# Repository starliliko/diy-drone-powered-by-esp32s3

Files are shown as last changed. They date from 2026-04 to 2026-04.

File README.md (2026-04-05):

# DIY-Drone

> 基于 ESP-Drone 二次开发的室内无刷四旋翼无人机，涵盖飞控固件、机架设计与地面站全链路。

本项目以 Espressif [ESP-Drone](https://github.com/espressif/esp-drone) 飞控工程为基础，将原有微型有刷方案重构为 **更大轴距、无刷电机驱动** 的四旋翼平台，并围绕该平台完成了飞控适配、传感器链路优化、安全机制完善、机架结构设计以及地面站调试闭环搭建。

## 项目亮点

| 方向 | 内容 |
|---|---|
| **飞控适配** | 基于 ESP32-S3 / ESP-IDF / FreeRTOS，对 ESP-Drone 飞控架构进行重构与平台适配 |
| **传感器链路** | 接入 BMI088（SPI）、气压计、光流，完成中断驱动采集、零偏校准、低通 / 陷波滤波 |
| **状态估计与控制** | 卡尔曼估计器、PID 级联控制、多飞行模式（姿态 / 定高 / 定点）、多控制源优先级切换 |
| **安全机制** | 遥控失联降级、控制源超时切换、解锁保护、异常紧急停机 |
| **机架设计** | Autodesk Inventor 建模 → 3D 打印打样 → 实机装配 → 结构迭代 |
| **地面站** | Node.js + WebSocket，实时遥测、3D 姿态可视化、远程控制、电机测试 |

## 仓库结构

```text
DIY-DRONE/
├── docs/                  # 项目文档与开发记录
├── mechanical/            # 机架 CAD 源文件、导出图纸、打印件
│   ├── 新版 4.5/          #   当前版本
│   └── 旧完整版/          #   早期版本备份
├── software/
│   ├── firmware/          # 飞控固件（ESP-IDF 工程）
│   └── groundstation/     # 地面站（Node.js）
├── LICENSE
└── README.md
```

## 系统架构

```text
┌──────────────┐  TCP/WiFi   ┌──────────────┐  WebSocket  ┌──────────────┐
│   ESP32-S3   │ ──────────▶ │  Node.js     │ ──────────▶ │   浏览器      │
│   飞控固件    │ ◀────────── │  地面站服务    │ ◀────────── │   Web UI     │
└──────────────┘   控制指令   └──────────────┘   操作指令   └──────────────┘
       │
       ├── BMI088（SPI）· 加速度 / 陀螺仪
       ├── 气压计（I2C）· 高度估计
       ├── 光流（UART）· 水平位置
       └── SBUS 遥控器 · 最高优先级控制源
```

### 飞控固件 — `software/firmware/`

- 传感器驱动与中断采集
- 卡尔曼状态估计、PID 级联控制
- 多飞行模式（姿态稳定 / 定高 / 定点）
- 多控制源优先级管理（SBUS > TCP > CRTP）
- 失联降级、解锁保护、紧急停机等安全链路

### 地面站 — `software/groundstation/`

- 遥测仪表盘与 Three.js 3D 姿态可视化
- 解锁 / 起飞 / 降落 / 紧急停止 等飞行控制
- 独立电机推力测试
- WebSocket 实时双向通信

### 机架 — `mechanical/`

- Autodesk Inventor 全参数化建模
- 电机 / 桨叶 / 电池 / 电调安装适配
- 重心布局、减振结构、强度优化
- 3D 打印打样与实物装配验证

## 技术栈

| 类别 | 技术 |
|---|---|
| MCU / 平台 | ESP32-S3 |
| 固件框架 | ESP-IDF 5.x · FreeRTOS |
| 传感器 | BMI088 · BMP388 · PMW3901 光流 |
| 通信接口 | SPI · I2C · UART · TCP · WiFi |
| 控制与估计 | PID 级联 · 扩展卡尔曼滤波 · 多模式状态管理 |
| 地面站 | Node.js · Express · WebSocket · Three.js |
| 机械设计 | Autodesk Inventor · FDM 3D 打印 |

## 当前进展

- [x] 无刷四旋翼整机方案设计与样机装配
- [x] 飞控固件迁移、传感器接入与基础飞行功能打通
- [x] 地面站开发与调试链路搭建
- [x] 基础实飞测试
- [ ] 飞行稳定性与控制参数持续优化
- [ ] 地面站功能完善（数据记录 / 回放 / 图表）
- [ ] 机架结构持续迭代（减振、重心、安装布局）

## 声明

本项目基于 [ESP-Drone](https://github.com/espressif/esp-drone) 飞控工程进行二次开发，部分飞控架构与算法实现参考了相关开源飞控项目。本仓库重点展示在此基础上完成的平台重构、软硬件适配、整机设计与实机调试工作。

## 许可证

[GPL-3.0](LICENSE)

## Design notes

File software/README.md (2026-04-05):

# Software — 软件系统

> 飞控固件与地面站，构成 DIY-Drone 的完整软件链路。

## 目录结构

```text
software/
├── firmware/          # 飞控固件（ESP-IDF 工程）
└── groundstation/     # 地面站（Node.js Web 应用）
```

## 飞控固件 — `firmware/`

基于 ESP-IDF 5.x 构建，运行在 ESP32-S3 上。

| 模块 | 说明 |
|---|---|
| 传感器驱动 | BMI088（SPI）、气压计（I2C）、光流（UART）中断采集与滤波 |
| 状态估计 | 扩展卡尔曼滤波器，融合 IMU / 气压 / 光流 |
| 控制链路 | PID 级联：位置 → 速度 → 姿态 → 电机输出 |
| 飞行模式 | 姿态稳定 · 定高 · 定点 |
| 安全机制 | 遥控失联降级 · 控制源超时切换 · 解锁保护 · 紧急停机 |
| 通信 | CRTP/WiFi · SBUS 遥控 · TCP 远程服务器 |

### 快速构建

```bash
cd software/firmware
idf.py set-target esp32s3
idf.py build
idf.py -p COMx flash monitor
```

> 需要 ESP-IDF 5.x 环境。Windows 下可通过 ESP-IDF PowerShell 或 VS Code ESP-IDF 扩展进入环境。

## 地面站 — `groundstation/`

基于 Node.js 的 Web 地面站，提供遥测可视化与远程控制能力。

| 功能 | 说明 |
|---|---|
| 遥测仪表盘 | 姿态角 · 位置 · 速度 · 电池状态 · 飞行模式 |
| 3D 可视化 | Three.js 实时姿态渲染 |
| 飞行控制 | 解锁 / 上锁 · 起飞 / 降落 · 悬停 · 紧急停止 |
| 电机测试 | 独立电机推力测试工具 |

### 快速启动

```bash
cd software/groundstation
npm install
npm start
# 浏览器访问 http://localhost:3000
```

## 开发建议

- 飞控开发：以 `software/firmware/` 为工作区，使用 ESP-IDF 工具链
- 地面站开发：进入 `software/groundstation/`，使用 `npm run dev` 热重载开发

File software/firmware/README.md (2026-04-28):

# ESP-Drone Firmware (ESP32-S3)

> 基于 [Bitcraze Crazyflie](https://github.com/bitcraze/crazyflie-firmware) + [Espressif ESP-Drone](https://github.com/espressif/esp-drone) 的二次开发 DIY 飞控固件。
> 目标硬件:**ESP32-S3** + BMI088 (SPI) + MS5611 (I2C) + QMC5883P (I2C) + MTF01 (UART/光流)。

---

## 1. 工具链

| 项目 | 版本 |
| --- | --- |
| ESP-IDF | **5.5.1** |
| 目标芯片 | esp32s3 |
| 编译框架 | CMake + Ninja |
| 调试器 | ESP-PROG / 内置 USB-JTAG |

确认环境:

```powershell
idf.py --version           # 应输出 v5.5.1
echo $env:IDF_TARGET        # 应为 esp32s3 (或留空让 sdkconfig 决定)
```

---

## 2. 构建 / 烧录 / 监控

```powershell
# 配置(首次必做,选 STA SSID/密码、地面站 IP)
idf.py menuconfig
#   → diy-drone config → wireless config
#   → Component config → ESP-Drone Config

# 构建
idf.py build

# 烧录 + 监控(替换 COM 口)
idf.py -p COM3 flash monitor
#   退出 monitor: Ctrl + ]

# 单独烧录 / 单独监控
idf.py -p COM3 flash
idf.py -p COM3 monitor

# 清理
idf.py fullclean
```

---

## 3. 目录结构

```text
firmware/
├── main/                       # 应用入口
│   └── main.c                  #   app_main(): NVS → platformInit → BMI088 自检
├── components/
│   ├── config/                 # 全局配置头(任务优先级、栈、GPIO)
│   ├── platform/               # 硬件平台抽象 (EP20 / EP30 等型号)
│   ├── drivers/                # 驱动层
│   │   ├── general/            #   电机 PWM / SBUS / WiFi / MTF01 光流 / LED / 蜂鸣器 / ADC
│   │   ├── i2c_bus/            #   I2C 总线
│   │   ├── i2c_devices/        #   MS5611 气压计 / QMC5883P 磁力计 / EEPROM
│   │   └── spi_devices/        #   BMI088 IMU
│   ├── core/crazyflie/         # 飞控核心(Crazyflie 框架)
│   │   ├── hal/                #   传感器统一抽象 (sensors_bmi088_spi_ms5611_qmc5883p.c)
│   │   ├── modules/            #   stabilizer / commander / estimator / controller / ...
│   │   └── utils/              #   工具函数
│   └── lib/dsp_lib/            # Xtensa DSP 库(矩阵 / PID / 滤波)
├── docs/                       # 中文设计与调试文档(详见 docs/README.md)
├── partitions.csv              # 分区表 (factory 2 MB + storage 1 MB)
├── sdkconfig.defaults          # 默认配置
└── CMakeLists.txt
```

---

## 4. 关键任务

| 任务 | 文件 | 频率 / 优先级 | 说明 |
| --- | --- | --- | --- |
| `sensorsTask` | `core/crazyflie/hal/src/sensors_bmi088_spi_ms5611.c` | 1 kHz / 6 | BMI088 中断驱动,IMU 读取 + 磁力计 50 Hz 分频 + 倾斜补偿 yaw |
| `stabilizerTask` | `modules/src/stabilizer.c` | 1 kHz / 7 | 主稳定器循环:估计器 → 控制器 → 电机分配 |
| `estimatorKalmanTask` | `modules/src/estimator_kalman_task.c` | 500 Hz 预测 / 4 | EKF;TOF 主观测,Baro 可选(`KALMAN_USE_BARO_UPDATE`) |
| `commanderTask` | `modules/src/commander.c` | 事件 / 3 | 多源 setpoint 聚合(SBUS > TCP > CRTP) |
| `extRxTask` | `modules/src/extrx.c` | UART / 2 | SBUS 解析 |
| `remoteServerTx/Rx` | `modules/src/remote_server.c` | 100 Hz 上行 / 2 | MAVLink v2 + 私有 0xABCD 双栈,WiFi/TCP+UDP |
| `crtpRx/Tx` | `modules/src/crtp.c` | 事件 / 2 | CRTP(WiFi UDP / cfclient) |
| `param/log` | `modules/src/{param,log}.c` | 事件 / 2 | 参数与日志框架(注册/查询/订阅) |

详见 [docs/双核部分.md](docs/双核部分.md) 与 [docs/无人机控制流程.md](docs/无人机控制流程.md)。

---

## 5. 状态估计与控制

- **姿态解算**:`sensfusion6.c`(陀螺+加速度互补滤波)+ 磁力计倾斜补偿 yaw。
- **位置/高度估计**:`estimator_kalman.c` + `kalman_core.c`,21 维状态向量。
  - 高度主观测:**TOF (MTF01)**,默认开启
  - Baro:代码已就位,默认未编译开启
  - 详见 [docs/卡尔曼估计器详解.md](docs/卡尔曼估计器详解.md) / [docs/飞控高度估计总结与项目现状.md](docs/飞控高度估计总结与项目现状.md)
- **姿态控制**:`controller_pid.c`(默认)/ `controller_indi.c` / `controller_mellinger.c`,通过 `STABILIZER_CONTROLLER_TYPE` 切换。
- **电机分配**:`power_distribution_stock.c`(X 型四旋翼)。

---

## 6. 通信链路

```text
                       ┌─────────────────────┐
                       │      ESP32-S3       │
                       └─────────┬───────────┘
                                 │
   ┌─────────────────────────────┼────────────────────────┐
   │                             │                        │
   ▼ AP (192.168.43.42)          ▼ STA (路由器)            ▼ UART
 cfclient / 手机 APP        Ground Station (本仓 GS)    SBUS 接收机
 (CRTP over UDP)            ├─ TCP 8080  MAVLink/0xABCD  (extrx.c)
                            └─ UDP 8082  ESPU 高频遥测
                            └─ UDP 8081  ESPD 自动发现
```

- 地面站协议:固件 `remote_server.c` 已实现 **MAVLink v2 双栈**(HEARTBEAT / SYS_STATUS / ATTITUDE / SERVO_OUTPUT_RAW / LOCAL_POSITION_NED / HIGHRES_IMU / PARAM_SET / MANUAL_CONTROL / COMMAND_LONG / COMMAND_ACK)。
- 长参数键(>16 B)使用别名:`pa_*` ↔ `pid_attitude.*`,`pp_*` ↔ `posCtlPid.*`。
- 详见 [docs/远程服务器通信配置指南.md](docs/远程服务器通信配置指南.md) / [docs/MAVLink重构方案.md](docs/MAVLink重构方案.md) / [docs/通信部分.md](docs/通信部分.md)。

---

## 7. 配置项 (`menuconfig`)

主要分组:

```
diy-drone config
 ├── platform                  机型(EP20/EP30)、传感器组合
 └── wireless config
     ├── STA Mode & Remote Server   STA SSID/密码、远程服务器 IP/端口
     └── Remote Server Settings     心跳/遥测频率、重连间隔

Component config
 └── ESP-Drone Config
     ├── Stabilizer            控制器类型、控制频率
     ├── Estimator             EKF 开关、Baro 更新开关
     └── Debug                 日志级别、模块过滤
```

参数(运行时,通过 `param.c` 注册):见 [docs/程序配置结构.md](docs/程序配置结构.md)。

---

## 8. 分区表

[`partitions.csv`](partitions.csv):

| 名称 | 类型 | 大小 | 用途 |
| --- | --- | --- | --- |
| nvs | data, nvs | 24 KB | NVS(WiFi/参数) |
| phy_init | data, phy | 4 KB | RF 校准 |
| factory | app, factory | 2 MB | 固件镜像 |
| storage | data, spiffs | 1 MB | 可选文件系统 |

---

## 9. 调试

- **日志**:`idf.py monitor`,模块前缀如 `[STAB] [SENSORS] [EKF] [REMOTE] [PARAM]`。
- **JTAG**:见 [docs/ESP32S3_VSCode调试指南.md](docs/ESP32S3_VSCode调试指南.md)。
- **PID 实时调参**:用配套地面站 [`groundstation/`](../groundstation/),PID 写入持久化 + 上电自动下发。
- **磁力计校准**:地面站 🧭 标签页,3D 点云采集后自动写 `mag.offX/Y/Z` + `mag.scaleX/Y/Z`。
- **VOFA+ 频谱**:`groundstation` 转发 13 通道 FireWater UDP 8083,详见 [docs/频谱分析与滤波调参指南.md](docs/频谱分析与滤波调参指南.md)。

---

## 10. 文档

中文设计与调试文档全在 [docs/](docs/) 下,导航见 [docs/README.md](docs/README.md)。

---

## 11. 配套地面站

详见 [`../groundstation/`](../groundstation/)(Node.js,启动 `npm start` → <http://localhost:3000>)。

---

## 12. 许可

GPL-3.0(来自上游 Crazyflie 与 Espressif ESP-Drone)。

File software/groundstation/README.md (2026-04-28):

# ESP-Drone Ground Station (QGC Lite)

> 基于 Node.js 的 ESP32-S3 飞控配套地面站。提供遥测可视化、3D 姿态、飞行控制、PID 调参、磁力计校准、电机/ESC 测试,以及向 [VOFA+](https://www.vofa.plus/) 的实时数据转发。

---

## 1. 功能概览

| 标签页 | 功能 |
| --- | --- |
| 📊 飞行监控 | 姿态/电机/电池/保护状态实时仪表盘 + Three.js 3D 姿态 + 飞行控制按钮 |
| ⚙️ 电机测试 | 单/全/顺序模式电机测试,3 秒无操作自动停止;ESC 行程校准 |
| 🎛️ PID 调参 | `pid_attitude` / `pid_rate` / `velCtlPid` / `posCtlPid` 实时曲线 + 参数表;持久化到 `data/pid_profile.json`,飞控连接后自动下发 |
| 🧭 磁力计校准 | 3D 点云采集、`offX/Y/Z` + `scaleX/Y/Z` 写回飞控 |

通信特性:

- **双协议栈**:`legacy`(自定义 0xABCD 二进制)/ `mavlink`(MAVLink v2)/ `dual`(同时兼容)
- **TCP** 接收飞控连接,**UDP** 接收高频遥测,**UDP 广播** 自动发现地面站
- **WebSocket** 推送给浏览器,**UDP/FireWater** 转发给 VOFA+
- 多飞控连接 + 多浏览器客户端

---

## 2. 快速开始

```bash
npm install
npm start          # 生产
npm run dev        # 开发(--watch 热重载)
```

服务端口(详见 [`src/config.js`](src/config.js)):

| 端口 | 协议 | 用途 |
| --- | --- | --- |
| 3000 | HTTP / WebSocket | Web 界面与浏览器双向通道 |
| 8080 | TCP | 飞控主连接(控制 + 心跳 + 参数) |
| 8081 | UDP 广播 | 地面站发现(`ESPD` 魔数) |
| 8082 | UDP | 飞控高频遥测上行(`ESPU` 魔数) |
| 8083 | UDP | VOFA+ FireWater 转发 |

打开浏览器访问 <http://localhost:3000>。

---

## 3. 飞控端配置

通过 `idf.py menuconfig` → `diy-drone config` → `wireless config`:

```
[*] Enable STA+AP Mode
    Router SSID = <你的 WiFi>
    Router Password = <密码>
[*] Enable Remote Server Connection
    Remote Server IP   = <运行地面站的电脑 IP>
    Remote Server Port = 8080
```

获取本机 IP(PowerShell):

```powershell
Get-NetIPAddress -AddressFamily IPv4 |
  Where-Object { $_.InterfaceAlias -notlike '*Loopback*' } |
  Select-Object IPAddress, InterfaceAlias
```

> 地面站启动时会向本网段广播 8081 端口,飞控可通过广播自动定位地面站(无需固定 IP)。

---

## 4. 项目结构

```text
groundstation/
├── server.js                    # 入口,实例化 DroneServer
├── package.json                 # express ^5 / ws ^8 / bonjour-service ^1
├── motor_test.js                # CLI 电机测试工具(直连飞控 TCP)
├── test-vofa-receiver.js        # VOFA+ UDP 接收测试器
├── data/
│   └── pid_profile.json         # PID 持久化(自动生成)
├── src/                         # 后端 (CommonJS)
│   ├── config.js                #   端口、协议模式、超时
│   ├── protocol.js              #   PacketType / FlightMode / ControlSource / 魔数
│   ├── parser.js                #   私有协议二进制编解码
│   ├── mavlink.js               #   MAVLink v2 编解码(最小子集)
│   ├── DroneClient.js           #   单架飞控连接(TCP + 双协议解析)
│   └── DroneServer.js           #   主服务: TCP/HTTP/WS/UDP/PID/VOFA
└── public/                      # 前端 (ES6 modules)
    ├── index.html
    ├── css/style.css
    └── js/
        ├── app.js               # 入口、模块装配、页面切换
        ├── websocket.js         # WS 连接、自动重连、心跳、日志
        ├── visualization.js     # Three.js 3D 飞机模型
        ├── dashboard.js         # 遥测仪表盘
        ├── control.js           # ARM/DISARM/TAKEOFF/LAND/RTL/HOVER
        ├── motorTest.js         # 电机测试 UI
        ├── pidTuner.js          # PID 实时曲线 + 参数表
        ├── magCalib.js          # 磁力计 3D 点云
        └── vofa-client.js       # VOFA+ 配置面板
```

---

## 5. 协议模式

[`src/config.js`](src/config.js) 中 `PROTOCOL_MODE` 决定与飞控通信的栈:

```js
PROTOCOL_MODE: 'mavlink',   // 'legacy' | 'mavlink' | 'dual'
```

- `legacy` — 仅自定义 `0xAB 0xCD` 二进制协议
- `mavlink` — 仅 MAVLink v2(默认,推荐)
- `dual` — 双栈识别;接收时按起始字节自动识别,发送时优先 MAVLink

> 切换模式后需重启服务,飞控端配置同步切换。在 `dual` 模式下,所有参数写入(电机/PID/磁力计)统一走 MAVLink 的 `PARAM_SET`,避免 CRTP 与 MAVLink 混合产生不一致。

### 参数键长度别名

MAVLink `PARAM_SET` 限制 param_id 为 16 字节,而部分参数键过长(如 `pid_attitude.roll_kp`)。系统使用以下别名,由固件 [`remote_server.c`](../firmware/components/core/crazyflie/modules/src/remote_server.c) 反向解析回原 (group, name):

| 别名前缀 | 实际组 |
| --- | --- |
| `pa_*` | `pid_attitude.*` |
| `pp_*` | `posCtlPid.*` |

其余短键直接使用。

---

## 6. REST API

| 方法 | 路径 | 功能 |
| --- | --- | --- |
| **状态** | | |
| GET | `/api/status` | 飞控连接列表 + WebSocket 客户端数 |
| **飞行控制** | | |
| POST | `/api/control` | `{cmdType, roll, pitch, yaw, thrust, mode}` |
| **电机测试** | | |
| POST | `/api/motor/set` | 单电机 `{motorId 0-3, thrust 0-65535}` |
| POST | `/api/motor/all` | 全部同推 `{thrust}` |
| POST | `/api/motor/sequential` | 顺序测试 `{thrust}` |
| POST | `/api/motor/estop` | 紧急停止(写 `motortest.estop=1`) |
| POST | `/api/esc/calibrate-first` | ESC 首次行程 `{stage: start\|finish\|abort}` |
| **磁力计** | | |
| POST | `/api/mag/calibrate/start` | `mag.calibrate=1` 开始采集 |
| POST | `/api/mag/calibrate/stop` | `mag.calibrate=0` 结束并固化 |
| POST | `/api/mag/param` | `{name, value, type}`,`name` ∈ `offX/Y/Z, scaleX/Y/Z, declination, yawStdDev, yawEn` |
| **PID** | | |
| GET | `/api/pid/profile` | 当前 PID 全量 |
| POST | `/api/pid/profile` | `{params: {"group.name": value, ...}}` 批量保存 |
| POST | `/api/pid/set` | `{group, name, value}` 单参,自动持久化 + 下发 |
| POST | `/api/pid/batch` | `{params: [{group, name, value}, ...]}` |
| **VOFA+** | | |
| POST | `/api/vofa/enable` | `{enabled: bool}` |
| GET | `/api/vofa/status` | 启停状态 + 客户端列表 |
| POST | `/api/vofa/add-client` | `{ip, port}` |
| POST | `/api/vofa/remove-client` | `{key: "ip:port"}` |

### WebSocket 消息

浏览器 → 服务端为 `{type, ...}` JSON;服务端 → 浏览器主要类型:

| type | 内容 |
| --- | --- |
| `telemetry` | `{client, data: {roll, pitch, yaw, motorOutputs[4], battery, flightMode, armingState, protection, ...}}` |
| `status` | 客户端连/断、协议模式 |
| `log` | 服务器日志推送 |

---

## 7. 工具脚本

### 电机直测 CLI

绕过地面站,直接连飞控(TCP 8080)发参数:

```bash
node motor_test.js stop
node motor_test.js sequential 30000
node motor_test.js single 0 25000
node motor_test.js all 20000
```

### VOFA+ UDP 接收器

用于在没有 VOFA+ 时验证转发链:

```bash
node test-vofa-receiver.js          # 默认端口 8083
node test-vofa-receiver.js 1347     # 指定端口
```

VOFA+ FireWater 通道顺序:`roll, pitch, yaw, gyroX, gyroY, gyroZ, accX, accY, accZ, M1, M2, M3, M4`(共 13 通道)。

---

## 8. 数据协议(私有 0xABCD)

仅 `legacy`/`dual` 模式使用,`mavlink` 模式可忽略本节。

```text
包头 (8 B):
┌──────┬──────┬─────────┬──────┬─────┬────────┐
│ 0xAB │ 0xCD │ Version │ Type │ Seq │ Length │
│  1B  │  1B  │   1B    │  1B  │ 2B  │   2B   │
└──────┴──────┴─────────┴──────┴─────┴────────┘
包体: 由 Type 决定
```

包类型见 [`src/protocol.js`](src/protocol.js):`HEARTBEAT 0x00` / `TELEMETRY 0x01` / `CONTROL 0x02` / `CRTP 0x03` / `ACK 0x04` / `CONFIG 0x05` / `LOG 0x06`。

UDP 高频遥测包前缀魔数为 `ESPU`(0x45 0x53 0x50 0x55),后接 1 字节类型 + 1 字节序号 + payload(同 TELEMETRY)。

---

## 9. 控制源优先级(飞控端)

飞控同时接收多路控制源,按优先级聚合,1 秒无数据自动降级:

| 优先级 | 源 |
| --- | --- |
| 3 | SBUS 遥控器 |
| 2 | TCP 地面站(本工程) |
| 1 | CRTP / WiFi(手机 APP / cfclient) |
| 0 | 无 |

详见固件 [`vehicle_state.c`](../firmware/components/core/crazyflie/modules/src/vehicle_state.c)。

---

## 10. 故障排除

| 现象 | 排查 |
| --- | --- |
| 飞控 TCP 连不上 | ① 防火墙放行 8080 ② 飞控/电脑同一网段 ③ 飞控 menuconfig 中 IP/Port 正确 ④ 试试 8081 广播自动发现 |
| 浏览器无遥测 | ① 左上角 WS 指示灯 ② 浏览器控制台错误 ③ 服务端日志 ④ `PROTOCOL_MODE` 与飞控一致 |
| PID 写入失败 | ① 飞控已连接 ② 参数键存在(看飞控 `param.c` LOG) ③ 长键应使用 `pa_*`/`pp_*` 别名 |
| 磁力计校准卡住 | ① 启动后必须缓慢翻滚画 8 字 30 s+ ② 检查 QMC5883P I2C 通信 |
| VOFA+ 无数据 | ① `/api/vofa/enable` 已启用 ② 客户端已 `add-client` ③ 防火墙放行 UDP 8083 |

---

## 11. 开发指南

```bash
npm start       # 生产模式
npm run dev     # 热重载
```

- **后端 (CommonJS)**:在 `src/DroneServer.js` 增加 `app.get/post('/api/...')`,在 `src/parser.js` 或 `src/mavlink.js` 增加编解码。
- **前端 (ES6 module)**:在 `public/js/` 新增模块,在 `app.js` 中 `import` 并装配,通过 `window.fnName = ...` 暴露给 HTML `onclick`。

技术栈:

| 层 | 选型 |
| --- | --- |
| 运行时 | Node.js ≥ 16 |
| HTTP | Express ^5 |
| WebSocket | ws ^8 |
| 服务发现 | bonjour-service / 自定义 UDP 广播 |
| TCP/UDP | 原生 `net` / `dgram` |
| 3D | Three.js r128 (CDN) |
| 实时图表 | uPlot 1.6 (CDN) |

---

## 12. 许可证

GPL-3.0,与 ESP-Drone 上游保持一致。

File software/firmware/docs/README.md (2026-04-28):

# Firmware 文档索引

> 本目录是 ESP-Drone 固件的中文设计/调试文档集合。文档由不同时间段累积,部分早期内容可能滞后于代码;**以本索引中标注 ✅ 的为最新主线参考**,标注 📌 的请以代码为准。

---

## 🚀 入门必读

- [系统架构与设计模式汇总.md](系统架构与设计模式汇总.md) — 整体架构 / FreeRTOS 多任务 / 设计模式 ✅
- [无人机控制流程.md](无人机控制流程.md) — 主控制循环执行链 ✅
- [双核部分.md](双核部分.md) — ESP32-S3 双核任务分配 ✅
- [程序配置结构.md](程序配置结构.md) — `param` / `log` 框架 + Kconfig ✅
- [各种端口定义.md](各种端口定义.md) — GPIO/SPI/I2C/UART 占用 ✅

## 🛰️ 状态估计

- [卡尔曼估计器详解.md](卡尔曼估计器详解.md) — EKF 实现详解 ✅
- [卡尔曼滤波.md](卡尔曼滤波.md) — 数学理论
- [飞控高度估计总结与项目现状.md](飞控高度估计总结与项目现状.md) — 高度估计当前状态(TOF 主、Baro 可选)✅
- [姿态解算参数调节指南.md](姿态解算参数调节指南.md) — 互补滤波调参
- [陀螺仪动态校准实现.md](陀螺仪动态校准实现.md) — 运行时陀螺零偏估计 ✅
- [频谱分析与滤波调参指南.md](频谱分析与滤波调参指南.md) — 配合地面站 VOFA+ 调振动滤波

## 🎮 控制与电机

- [电机控制.md](电机控制.md) — PWM / 电机分配 / 推力曲线
- [电机控制部分修改.md](电机控制部分修改.md) — 修改记录
- [电机测试系统使用指南.md](电机测试系统使用指南.md) — `motortest.*` 参数与地面站电机测试 ✅
- [pid参数.md](pid参数.md) — PID 默认值与含义
- [PID调试修复记录.md](PID调试修复记录.md) — 调试过程

## 📡 通信

- [通信部分.md](通信部分.md) — CRTP 协议栈 + 链路层(注:本工程链路实际由 `remote_server.c` 实现,而非上游 wifilink/espnow)📌
- [远程服务器通信配置指南.md](远程服务器通信配置指南.md) — Wi-Fi STA + 地面站 TCP 配置 ✅
- [MAVLink重构方案.md](MAVLink重构方案.md) — 已落地;固件端 MAVLink v2 双栈现已在 `remote_server.c` 中实现 ✅

## 🔌 传感器与驱动

- [BMI088驱动开发参考手册.md](BMI088驱动开发参考手册.md)
- [BMI088加速度计调试记录.md](BMI088加速度计调试记录.md)
- [BMI088传感器坐标轴映射修正.md](BMI088传感器坐标轴映射修正.md)
- [BMI088_SPI初始化问题排查记录.md](BMI088_SPI初始化问题排查记录.md)
- [光流，激光相关任务.md](光流，激光相关任务.md) — MTF01 + ToF

## 🛡️ 系统与安全

- [状态管理现状详解.md](状态管理现状详解.md) — `vehicle_state.c` 状态机
- [保护机制与停机链路对照表.md](保护机制与停机链路对照表.md) — 失控保护 ✅
- [ESP32同步机制详解.md](ESP32同步机制详解.md) — 信号量 / 队列 / Mutex
- [RTOS与操作系统基础笔记.md](RTOS与操作系统基础笔记.md)

## 🔧 工程化

- [ESP32S3_VSCode调试指南.md](ESP32S3_VSCode调试指南.md) — JTAG + GDB 调试 ✅
- [飞控软件详细报告.md](飞控软件详细报告.md) — 总结报告
- [flix_vs_diy-drone_差异对比.md](flix_vs_diy-drone_差异对比.md) — 与 flix 项目对比
- [嵌入式实习面试补强清单.md](嵌入式实习面试补强清单.md) — 学习路径
- [gitlab 域名.md](gitlab%20域名.md)
- [11.25.md](11.25.md) — 阶段性记录

---

## 📌 已知滞后点

- `通信部分.md` 中描述的链路层文件(`wifilink.c` / `espnow_ctrl.c`)是上游 Crazyflie 命名,本工程实际由 [`remote_server.c`](../components/core/crazyflie/modules/src/remote_server.c) 统一处理 WiFi/TCP/UDP 与 MAVLink 双栈。
- `MAVLink重构方案.md` 中的"固件端最小改造清单"已全部完成,该文档现作为协议参考保留。
- 本目录的传感器型号以代码为准:**BMI088 + MS5611 + QMC5883P + MTF01**(部分早期文档残留 MPU6050 / HMC5883L / PMW3901 等上游名称)。

如发现文档与代码不一致,优先信任代码,并欢迎提交修订。

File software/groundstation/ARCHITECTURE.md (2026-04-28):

# ESP-Drone Ground Station — 架构设计

> 同步代码状态:已实现完整 MAVLink v2 双栈、UDP 高频遥测、UDP 广播发现、VOFA+ 转发、PID 持久化与自动下发、磁力计/电机/ESC 完整调试链。

---

## 1. 系统架构

```text
┌──────────────────────────────────────────────────────────────┐
│                     ESP32-S3 飞控固件                         │
│        (FreeRTOS · Crazyflie 框架 · MAVLink/CRTP)            │
└────────┬───────────────┬───────────────────┬─────────────────┘
         │ TCP 8080      │ UDP 8082          │ UDP 8081
         │ MAVLink/0xABCD│ ESPU 高频遥测     │ ESPD 广播发现
         ▼               ▼                   ▲
┌──────────────────────────────────────────────────────────────┐
│              DroneServer (Node.js · server.js)               │
│  ┌────────────────────────────────────────────────────────┐  │
│  │ TCP server  ──→ DroneClient × N (per-IP)               │  │
│  │ UDP telemetry server                                   │  │
│  │ Discovery broadcaster (向 192.168.x.255)               │  │
│  │ PID profile (data/pid_profile.json)                    │  │
│  │ Express HTTP + WebSocket                               │  │
│  │ VOFA+ UDP forwarder (FireWater)                        │  │
│  └────────────────────────────────────────────────────────┘  │
└─────────┬───────────────────────────────────────┬────────────┘
          │ HTTP/WS 3000                          │ UDP 8083
          ▼                                       ▼
   ┌─────────────┐                          ┌──────────┐
   │  Browser    │                          │  VOFA+   │
   │  (4 tabs)   │                          │  /其他   │
   └─────────────┘                          └──────────┘
```

---

## 2. 后端模块 (`src/`)

| 模块 | 类/导出 | 职责 |
| --- | --- | --- |
| `config.js` | 常量对象 | 端口、`PROTOCOL_MODE`、超时、缓冲上限 |
| `protocol.js` | 枚举 + 魔数 | `PacketType` / `FlightMode` / `ControlSource` / `ControlCmdType` / `DISCOVERY_MAGIC` (`ESPD`) / `UDP_TELEMETRY_MAGIC` (`ESPU`) |
| `parser.js` | 函数集 | 私有协议:`parseHeader` / `parseTelemetry` / `createHeader` / `createControlCommand` |
| `mavlink.js` | 函数集 | MAVLink v2 帧编/解码、X25 CRC、消息子集 |
| `DroneClient.js` | `class DroneClient` | 单架飞控连接抽象。维护 RX 缓冲 → 双协议帧分离 → 心跳 → `sendControl` / `sendParamSet` |
| `DroneServer.js` | `class DroneServer` | 主服务,聚合一切:TCP/HTTP/WS/UDP × 3、PID 持久化、VOFA 转发、所有 REST API |

### `DroneServer` 关键成员

```js
this.clients         // Map<remoteAddr, DroneClient>
this.clientsByIP     // Map<droneIP, DroneClient>  // 用于匹配 UDP 遥测
this.webClients      // Set<WebSocket>
this.tcpServer / httpServer / wss
this.discoverySocket / udpTelemetrySocket / vofaSocket
this.pidProfile      // Map<"group.name", float>
this.vofaClients     // Map<"ip:port", {ip, port}>
```

启动入口:`start()` → `startTCPServer()` + `startWebServer()` + `startDiscoveryBroadcast()` + `startUDPTelemetryServer()` + `startVofaServer()`。

### PID 持久化与自动下发

- 文件:`data/pid_profile.json`,结构 `{version, updatedAt, params: {"group.name": value}}`
- 启动时 `loadPidProfile()` 读入 `Map`
- 飞控 TCP 连接建立 800 ms 后自动 `applyPidProfileToClient(client)`,逐条 `sendParamSet(group, name, FLOAT, value)`
- API `/api/pid/set` 与 `/api/pid/batch` 写入即刻保存 + 下发所有在线飞控
- 允许的 group:`pid_attitude` / `pid_rate` / `velCtlPid` / `posCtlPid`(白名单)

---

## 3. 前端模块 (`public/js/`)

```text
app.js (入口)
 ├── visualization.js   Three.js 飞机模型 / OrbitControls
 ├── websocket.js       WS 连接 + 自动重连 + 心跳 + 日志
 ├── dashboard.js       仪表盘 DOM 更新
 ├── control.js         ARM/DISARM/TAKEOFF/LAND/RTL/HOVER/远程控制模式
 ├── motorTest.js       4 滑块 + 单/全/顺序模式 + 3s 超时自停
 ├── pidTuner.js        uPlot 实时曲线 + 参数表 + REST 调用
 ├── magCalib.js        Three.js 3D 点云 + 校准状态机
 └── vofa-client.js     VOFA+ 客户端管理面板
```

`app.js` 装配顺序:

```js
viz.initThreeJS();
ws.connectWS();
ws.setTelemetryCallback(dash.updateDashboard);
ws.setMotorCallback(motor.updateMotorReadings);
ws.setLogCallback(consoleLog);
pid.init();   mag.init();   vofa.init();
```

全局函数通过 `window.fnName = ...` 暴露给 HTML `onclick`(`switchPage`、`sendAction`、`updateMotor` 等)。

---

## 4. 关键数据流

### 4.1 高频遥测 (UDP 上行)

```
ESP32 → UDP 8082 (ESPU 头 + payload)
         ↓
DroneServer.startUDPTelemetryServer
  → parseTelemetry(payload)
  → findClientByIP(rinfo.address) → client.latestTelemetry
  → broadcastTelemetry(addr, data)
        ├→ 所有 WS 客户端: {type:'telemetry', client, data}
        └→ 所有 vofaClients: FireWater 文本(13 通道 + '\n')
```

### 4.2 PID 调参

```
浏览器 pidTuner.js
  → fetch('/api/pid/set', {group, name, value})
DroneServer
  → normalizePidParam(白名单/类型)
  → mergePidProfileEntries → savePidProfile(JSON 落盘)
  → applyPidParamToAllClients
       → DroneClient.sendParamSet (MAVLink PARAM_SET, FLOAT)
            ↓ 长键应用别名 (pa_*/pp_*)
飞控 remote_server.c
  → 反向解析别名 → paramGetVarId → paramSetFloat
```

### 4.3 磁力计校准

```
浏览器 → POST /api/mag/calibrate/start
  → mag.calibrate=1 (UINT8)
飞控 sensors_bmi088_spi_ms5611.c 进入采集状态
浏览器周期性接收 mag.x/y/z (LOG) → 3D 点云渲染
浏览器 → POST /api/mag/calibrate/stop
  → mag.calibrate=0,固件计算 offset/scale,自动落参数
浏览器 → POST /api/mag/param  // 可手动写 declination/yawStdDev/yawEn
```

### 4.4 控制下行

```
浏览器按钮 → control.sendAction
  → fetch('/api/control', {cmdType, ...})
DroneServer.forEachDroneClient → DroneClient.sendControl
  → 按 PROTOCOL_MODE 选择 MAVLink MANUAL_CONTROL/COMMAND_LONG
    或 legacy CONTROL 包
TCP 8080 → 飞控
```

### 4.5 自动发现

```
DroneServer.startDiscoveryBroadcast
  → 每 DISCOVERY_INTERVAL ms 向 192.168.x.255 + 255.255.255.255
    发送 [ESPD][TCP_PORT][UDP_TELEMETRY_PORT]
飞控 收到广播后建立 TCP 8080 连接 + UDP 8082 上行
```

---

## 5. WebSocket 消息

浏览器 → 服务端:统一 `{type, ...}` JSON,目前服务端主要由 REST 驱动,WS 主要用于推送。

服务端 → 浏览器:

| type | 关键字段 |
| --- | --- |
| `telemetry` | `client`, `data: {roll,pitch,yaw, gyro, acc, motorOutputs[4], battery, flightMode, armingState, controlSource, protection}` |
| `status` | `clients[]`, `webClients`, `protocolMode` |
| `log` | `level`, `msg` |

---

## 6. 协议适配层 (`DroneClient`)

接收路径:

```
TCP onData → 累积 RX buffer
  → 帧分离循环:
      if buf[0:2] == AB CD:           ── legacy
         按 (Type, Length) 取出整帧 → parser.parseXxx
      elif buf[0] in {0xFD, 0xFE}:    ── MAVLink v2/v1
         解析包头 → 取出 payload → 校验 X25 + extra CRC
         分发到 onAttitude / onSysStatus / onParamValue / ...
      else:
         丢弃 1 字节,继续重同步
  → 缓冲超过 RX_BUFFER_MAX_BYTES 时清空,防 DoS
```

发送路径(`PROTOCOL_MODE` 决定):

| 模式 | sendControl | sendParamSet |
| --- | --- | --- |
| `legacy` | 自定义 0xABCD CONTROL 包 | 不支持(仅 MAVLink 通道) |
| `mavlink` | MANUAL_CONTROL / COMMAND_LONG | PARAM_SET + 16B 别名 |
| `dual` | 优先 MAVLink | PARAM_SET |

---

## 7. 部署

### 开发

```bash
npm install
npm run dev
```

### 生产

```bash
npm install --omit=dev
NODE_ENV=production npm start
```

### Nginx 反代

```nginx
location / {
    proxy_pass http://localhost:3000;
    proxy_http_version 1.1;
    proxy_set_header Upgrade $http_upgrade;
    proxy_set_header Connection "upgrade";
    proxy_set_header Host $host;
}
```

> TCP 8080 与 3 个 UDP 端口需直连飞控所在网段,通常无法走 7 层反代。

---

## 8. 扩展点

- **新控制指令**:`protocol.js` 加 `ControlCmdType` → `parser.js` 编码 → `control.js` 调用 → 必要时固件 `crtp_commander_*` 处理。
- **新遥测字段**:固件 `remote_server.c` 加入 MAVLink 消息 → `mavlink.js` 解码 → `dashboard.js` 渲染。
- **新参数面板**:`pidTuner.js` 是模板,组别加入 `ALLOWED_PID_GROUPS` 即可复用持久化机制。
- **历史回放**:`DroneServer.broadcastTelemetry` 是单一汇聚点,接 SQLite/MQTT 即可落盘。

---

## 9. 性能与限制

| 维度 | 数值 |
| --- | --- |
| TCP 心跳超时 | 10 s (`HEARTBEAT_TIMEOUT`) |
| WS 心跳/超时 | 10 / 15 s |
| RX 缓冲上限 | 256 KB,超出清空(防恶意流) |
| 最大单包 | 8 KB |
| 浏览器遥测节流 | 10 ms(`WEB_TELEMETRY_INTERVAL`) |
| PID 自动下发延迟 | 飞控连接后 800 ms |
| 发现广播间隔 | 2 s |

---

## 10. 调试

```bash
# 健康检查
curl http://localhost:3000/api/status

# WebSocket 抓包
npx wscat -c ws://localhost:3000

# UDP 遥测旁观
node test-vofa-receiver.js 8082    # 临时接管 8082 不可用,使用 vofa-receiver 仅作为 8083 校验
```

服务端日志前缀约定:`[TCP] [HTTP] [Discovery] [UDP Telemetry] [vofa+] [PID] [API]`,便于过滤。

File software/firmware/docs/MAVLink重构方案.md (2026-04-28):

# MAVLink 重构方案（飞控 <-> 地面站）

> **状态更新**：本文原为重构设计讴商。到 2026-04 为止，本文描述的地面站侧与固件侧双栈都已实现：
>
> - 地面站：`groundstation/src/mavlink.js` + `DroneClient.js` 双栈解析
> - 固件：`components/core/crazyflie/modules/src/remote_server.c` 完整实现 MAVLink v2 帧识别、CRC、`PARAM_SET` / `MANUAL_CONTROL` / `COMMAND_LONG` 下行与 `HEARTBEAT` / `SYS_STATUS` / `ATTITUDE` / `SERVO_OUTPUT_RAW` / `LOCAL_POSITION_NED` / `HIGHRES_IMU` 上行
> - 协议模式：`PROTOCOL_MODE = legacy | mavlink | dual`，默认 `mavlink`
>
> 第 4 节“固件端最小改造清单”仅作为历史参考，实际实现以代码为准。

## 1. 目标

将当前自定义二进制协议（magic=0xABCD）迁移到标准 MAVLink v2，并在迁移期支持双栈：

- `legacy`：仅旧协议
- `mavlink`：仅 MAVLink
- `dual`：双协议兼容（推荐灰度模式）

## 2. 当前已完成（地面站）

已在 groundstation 侧完成 MAVLink 双栈基础能力：

- 新增 MAVLink 最小编解码模块：
  - `groundstation/src/mavlink.js`
- `DroneClient` 支持 legacy + MAVLink 双栈解析与协议自动识别：
  - `groundstation/src/DroneClient.js`
- 新增协议模式开关：
  - `groundstation/src/config.js` -> `PROTOCOL_MODE`

## 3. 消息映射（建议）

### 3.1 飞控上行遥测

1. 姿态：`ATTITUDE (30)`
- roll/pitch/yaw（rad）
- rollspeed/pitchspeed/yawspeed（rad/s）

2. 电池：`SYS_STATUS (1)`
- `voltage_battery`（mV）
- `battery_remaining`（%）

3. 位置与速度：`LOCAL_POSITION_NED (32)`
- x/y/z（m）
- vx/vy/vz（m/s）

4. IMU 原始量：`HIGHRES_IMU (105)`
- xacc/yacc/zacc（m/s^2）
- xgyro/ygyro/zgyro（rad/s）

5. 心跳：`HEARTBEAT (0)`
- armed 状态放到 `base_mode` 的 `MAV_MODE_FLAG_SAFETY_ARMED`
- flight mode 通过 `custom_mode` 扩展（可选）

### 3.2 地面站下行控制

1. 手动姿态/油门：`MANUAL_CONTROL (69)`
- x/y/z/r 分别映射 pitch/roll/thrust/yaw

2. 解锁/上锁：`COMMAND_LONG (76)` + `MAV_CMD_COMPONENT_ARM_DISARM (400)`
- param1=1 解锁
- param1=0 上锁

3. 降落：`COMMAND_LONG (76)` + `MAV_CMD_NAV_LAND (21)`

4. 急停（兼容方案）
- 仍使用 `MAV_CMD_COMPONENT_ARM_DISARM`，param1=0，param2=21196（force disarm）

## 4. 固件端最小改造清单（已落地，仅备查）

> 以下所有项在 [`remote_server.c`](../components/core/crazyflie/modules/src/remote_server.c) 中都已完成。

1. ✅ 在 `remote_server.c` 增加 MAVLink 帧解析器
- 识别 `0xFD/0xFE` 起始字节
- 校验 X25 CRC + extra CRC
- 分发 `MANUAL_CONTROL` / `COMMAND_LONG`

2. ✅ 在 `handleControlPacket` 之外新增 MAVLink 控制入口
- `MANUAL_CONTROL -> commanderSetSetpoint(COMMANDER_PRIORITY_REMOTE)`
- `COMMAND_LONG(ARM/DISARM/LAND) -> vehicle_state` 对应接口

3. ✅ 在遥测任务中发送 MAVLink 消息
- 每个周期发送 `ATTITUDE`
- 低频发送 `SYS_STATUS`
- 视带宽发送 `LOCAL_POSITION_NED` / `HIGHRES_IMU`

4. ✅ 迁移期间保留 legacy 通道
- 由 Kconfig 控制：`REMOTE_PROTOCOL_MODE = LEGACY / MAVLINK / DUAL`

## 5. 风险与建议

1. 带宽与周期
- MAVLink 消息拆分后包数增多，建议对不同消息设置不同发送频率。

2. 坐标系与符号
- NED 与当前机体系/世界系存在符号差异，必须统一（尤其 z、yaw、roll）。

3. CRC 与 extra CRC
- 若消息 extra CRC 不匹配，会导致静默丢包。建议在固件加入统计计数器。

4. 回滚策略
- 默认先 `dual`，飞测稳定后切 `mavlink`。

## 6. 验收标准

1. 地面站显示稳定
- roll/pitch/yaw、电池、高度、速度正确更新

2. 控制正确
- ARM/DISARM/LAND/RPYT 可用，无方向反转

3. 故障恢复
- 断链重连后恢复正常

4. 兼容性
- `dual` 模式下 legacy 与 MAVLink 均可接入

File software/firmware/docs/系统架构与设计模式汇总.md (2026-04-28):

# ESP-Drone 系统架构与设计模式汇总

> 本文档汇总 ESP-Drone 飞控系统中涉及的核心概念、设计模式和知识点

---

## 目录

1. [系统架构概览](#系统架构概览)
2. [核心设计模式](#核心设计模式)
3. [FreeRTOS 多任务架构](#freertos-多任务架构)
4. [控制流与数据流](#控制流与数据流)
5. [关键知识点](#关键知识点)
6. [学习路径](#学习路径)

---

## 系统架构概览

### 系统初始化流程

```
main.c
  └─> platformInit()
      └─> systemLaunch()
          └─> systemTask (FreeRTOS 任务)
              ├─> 底层外设初始化 (LED, WiFi)
              ├─> 高级模块初始化 (System, Comm, Commander, SBUS, Stabilizer)
              ├─> 模块自检 (各模块 Test 函数)
              ├─> systemStart() (释放启动信号量)
              └─> workerLoop() (异步任务处理循环)
```

### 核心组件结构

```
components/
├── core/crazyflie/           # 飞控核心逻辑
│   ├── hal/                  # 硬件抽象层 (传感器、LED、WiFi)
│   ├── modules/              # 飞行模块
│   │   ├── stabilizer.c      # 稳定器 (1000Hz 控制循环)
│   │   ├── commander.c       # 指令管理器 (setpoint 分发)
│   │   ├── estimator_kalman.c # 卡尔曼滤波状态估计
│   │   ├── controller_pid.c  # PID 控制器
│   │   ├── extrx.c          # 外部接收器 (SBUS)
│   │   ├── worker.c         # 异步任务调度
│   │   └── system.c         # 系统主任务
│   └── utils/               # 工具函数
├── drivers/                 # 设备驱动
│   ├── i2c_devices/        # MS5611 气压计、QMC5883P 磁力计、EEPROM
│   ├── spi_devices/        # BMI088 IMU
│   └── general/            # 电机 PWM、WiFi、SBUS、MTF01 光流
└── platform/               # 硬件平台抽象
```

---

## 核心设计模式

### 1. 生产者-消费者模式 (Producer-Consumer Pattern)

**应用场景**: `worker.c` 异步任务调度系统

```
生产者 (任意任务)                 消费者 (workerLoop)
      │                                 │
      ├─ stabilizerTask               │
      ├─ commTask            队列      │
      ├─ extRxTask      ┌──────────┐  │
      │                 │          │  │
      └──workerSchedule→│ Queue(5) │──┤
                        │          │  │
                        └──────────┘  ▼
                                   workerLoop()
                                   执行任务
```

**关键代码**:
```c
// 生产者接口
int workerSchedule(void (*function)(void*), void *arg);

// 消费者循环
void workerLoop() {
  while (1) {
    xQueueReceive(workerQueue, &work, portMAX_DELAY);
    work.function(work.arg);
  }
}
```

**知识点**: 操作系统 - 进程同步、队列通信

---

### 2. 命令模式 (Command Pattern)

**应用场景**: 将函数调用封装为可传递的对象

```c
struct worker_work {
  void (*function)(void*);  // 命令（操作）
  void* arg;                // 参数（上下文）
};
```

**优势**:
- 操作可以被存储、排队、延迟执行
- 调用者和执行者解耦

**知识点**: 设计模式、函数指针、回调机制

---

### 3. 优先级调度与实时性保障

**应用场景**: FreeRTOS 任务优先级设计

```
优先级 7 (最高) ──> stabilizerTask   (1 kHz 飞控主循环)
优先级 6        ──> sensorsTask      (1 kHz 传感器读取)
优先级 4        ──> estimatorKalman  (500 Hz EKF 预测)
优先级 3        ──> commander / extRx (setpoint / SBUS)
优先级 2        ──> remoteServerRx/Tx (MAVLink/CRTP over WiFi)
优先级 1 (最低) ──> systemTask / workerLoop (异步任务)
```

**设计原则**:
- 高优先级任务不执行耗时操作
- 耗时操作通过 `workerSchedule()` 委托给低优先级任务
- 避免优先级反转

**知识点**: 操作系统 - 任务调度、实时系统设计

---

### 4. 分层架构

```
应用层         commander.c         (接收 setpoint)
                    ↓
控制层         controller_pid.c    (PID 控制算法)
                    ↓
估计层         estimator_kalman.c  (状态估计)
                    ↓
驱动层         sensors.c, motors.c (硬件接口)
                    ↓
硬件层         BMI088 (SPI), MS5611 + QMC5883P (I2C), 电机 PWM
```

**知识点**: 软件工程 - 模块化设计、分层架构

---

## FreeRTOS 多任务架构

### ESP32 双核 SMP 模式

```
ESP32-S3 双核架构
├── CPU0 (PRO_CPU)
│   ├── stabilizerTask (自动调度)
│   ├── extRxTask
│   └── ...
└── CPU1 (APP_CPU)
    ├── sensorsTask (自动调度)
    ├── remoteServerTx / remoteServerRx
    └── ...
```

**特性**:
- SMP (对称多处理): 两个核心地位相等
- FreeRTOS 自动将任务分配到两个核心
- 使用 `xTaskCreate` (非固定核心) 或 `xTaskCreatePinnedToCore` (固定核心)

**知识点**: 操作系统 - 多核架构、SMP vs AMP

---

### 任务同步机制

| 机制 | 用途 | ESP-Drone 中的应用 |
| --- | --- | --- |
| **信号量 (Semaphore)** | 资源计数、事件通知 | `canStartMutex` (启动同步) |
| **互斥锁 (Mutex)** | 保护共享资源 | I2C 总线互斥访问 |
| **队列 (Queue)** | 任务间通信 | `workerQueue`, `setpointQueue` |
| **中断控制** | 临界区保护 | `portENTER_CRITICAL()` |

**知识点**: 操作系统 - 进程同步、临界区

---

### systemStart() 启动同步机制

```c
// 初始化时创建互斥信号量并获取
xSemaphoreTake(canStartMutex, portMAX_DELAY);

// 其他任务等待启动
void systemWaitStart(void) {
  xSemaphoreTake(canStartMutex, portMAX_DELAY);
  xSemaphoreGive(canStartMutex);  // 立即释放
}

// 初始化完成后释放信号量
void systemStart() {
  xSemaphoreGive(canStartMutex);
}
```

**效果**: 所有任务阻塞等待，直到系统初始化完成

---

## 控制流与数据流

### 飞控主循环 (1000Hz)

```
sensorsTask (1 kHz)
    ↓ 读取传感器数据
sensors.c → BMI088 (IMU, SPI), MS5611 (气压计), QMC5883P (磁力计)
    ↓ 原始数据
estimatorKalmanTask
    ↓ 卡尔曼滤波融合
state_t (姿态、位置、速度估计)
    ↓
stabilizerTask (1000Hz)
    ↓ 获取 setpoint
commanderGetSetpoint()
    ↓
controller_pid.c (PID 控制)
    ↓
motorsSetRatio() (PWM 输出)
    ↓
电机旋转 → 飞行
```

---

### 控制指令优先级机制

```c
// commander.h
#define COMMANDER_PRIORITY_DISABLE 0  // 禁用
#define COMMANDER_PRIORITY_CRTP    1  // WiFi/手机APP
#define COMMANDER_PRIORITY_EXTRX   2  // 遥控器 (最高)
```

**数据流**:

```
手机APP (WiFi)                    遥控器 (SBUS)
    ↓                                ↓
crtpCommanderCB()                extRxTask()
    ↓                                ↓
commanderSetSetpoint(优先级1)    commanderSetSetpoint(优先级2)
    ↓                                ↓
          ┌──────────────────────────┐
          │  setpointQueue (队列)     │
          │  只有优先级 >= 当前优先级  │
          │  才能覆盖                 │
          └──────────────────────────┘
                    ↓
          commanderGetSetpoint()
                    ↓
              stabilizerTask
```

**安全设计**: 遥控器始终可以覆盖手机APP指令

---

### SBUS 接收器数据流

```
FS-I6X 遥控器
    ↓ 2.4GHz 无线
IA-10B 接收器
    ↓ SBUS 协议 (100000 baud, 8E2, 串口)
sbusReadFrame()  (sbus.c)
    ↓ 解析 16 通道数据
extRxDecodeChannels()  (extrx.c)
    ↓ 转换为 setpoint
    │ • Roll:  -20° ~ +20°
    │ • Pitch: -20° ~ +20°
    │ • Yaw:   -150°/s ~ +150°/s
    │ • Thrust: 0 ~ 65535
    ↓
commanderSetSetpoint(&extrxSetpoint, COMMANDER_PRIORITY_EXTRX)
```

---

## 关键知识点

### 1. 多态 (Polymorphism)

**定义**: 同一接口，不同实现，运行时决定调用哪个

**C语言实现** (函数指针):
```c
void (*function)(void*);  // 函数指针可以指向不同函数
work.function = saveConfig;
work.function = sendData;
work.function(arg);  // 运行时决定调用哪个
```

**C++实现** (虚函数):
```cpp
class Animal { virtual void speak() = 0; };
class Dog : public Animal { void speak() { cout << "汪"; } };
class Cat : public Animal { void speak() { cout << "喵"; } };
```

**知识来源**: 面向对象程序设计 (OOP)

---

### 2. 线程池 (Thread Pool)

**定义**: 预创建一组线程，重复利用执行任务

**标准线程池**:
```
任务队列 → [ Worker1, Worker2, Worker3, ... ] → 并行执行
```

**ESP-Drone Worker** (简化版):
```
任务队列 → [ Worker (单线程) ] → 串行执行
```

**为什么简化?**
- 嵌入式内存有限
- 串行执行足够应对非实时任务
- 降低复杂度，提高可靠性

**知识来源**: 操作系统、并发编程

---

### 3. CRTP 协议 (Crazy RealTime Protocol)

**定义**: Crazyflie 自定义的轻量级通信协议

**数据包结构**:
```c
typedef struct {
  uint8_t header;     // 端口 + 通道
  uint8_t size;       // 数据长度
  uint8_t data[30];   // 载荷
} CRTPPacket;
```

**端口分配**:
- `CRTP_PORT_CONSOLE` (0) - 调试输出
- `CRTP_PORT_PARAM` (2) - 参数读写
- `CRTP_PORT_SETPOINT` (3) - 控制指令
- `CRTP_PORT_MEM` (4) - 内存管理
- `CRTP_PORT_LOG` (5) - 日志数据

**传输层**: WiFi UDP / TCP,统一由 `remote_server.c` 实现(MAVLink v2 + 私有 0xABCD 双栈)

---

### 4. 参数与日志系统

**参数系统** (可读写):
```c
PARAM_GROUP_START(controller)
PARAM_ADD(PARAM_FLOAT, kp_roll, &kp_roll)
PARAM_ADD(PARAM_FLOAT, ki_roll, &ki_roll)
PARAM_GROUP_STOP(controller)
```

**日志系统** (只读):
```c
LOG_GROUP_START(stabilizer)
LOG_ADD(LOG_FLOAT, roll, &state.attitude.roll)
LOG_ADD(LOG_FLOAT, pitch, &state.attitude.pitch)
LOG_GROUP_STOP(stabilizer)
```

**应用**: 通过 cfclient (PC客户端) 实时调参和监控

---

### 5. 静态内存分配

**FreeRTOS 两种创建方式**:

| 方式 | 函数 | 内存分配 |
| --- | --- | --- |
| 动态分配 | `xTaskCreate` | 从堆分配 |
| 静态分配 | `xTaskCreateStatic` | 编译时分配 |

**ESP-Drone 全部使用静态分配**:
```c
STATIC_MEM_TASK_ALLOC(systemTask, SYSTEM_TASK_STACKSIZE);
STATIC_MEM_TASK_CREATE(systemTask, systemTask, SYSTEM_TASK_NAME, NULL, SYSTEM_TASK_PRI);
```

**优势**:
- 避免堆碎片
- 可预测内存使用
- 提高可靠性

---

## 学习路径

### 基础课程

| 课程 | 涵盖知识点 |
| --- | --- |
| **C语言程序设计** | 指针、函数指针、结构体 |
| **数据结构** | 队列、链表、抽象数据类型 |
| **面向对象程序设计** | 继承、多态、虚函数 |

### 核心课程

| 课程 | 涵盖知识点 |
| --- | --- |
| **操作系统** | 进程/线程、同步机制、调度、生产者-消费者 |
| **嵌入式系统** | RTOS、实时调度、中断处理 |
| **控制理论** | PID控制、卡尔曼滤波、状态估计 |

### 进阶课程

| 课程 | 涵盖知识点 |
| --- | --- |
| **并发编程** | 线程池、异步编程、锁与无锁 |
| **设计模式** | 命令模式、观察者模式、工厂模式 |
| **软件工程** | 模块化设计、分层架构 |

---

### 推荐学习资源

**教材**:
- 《操作系统概念》(恐龙书) - 进程同步、线程
- 《现代操作系统》(Tanenbaum) - 生产者消费者、IPC
- 《C++ Primer》 - 多态、虚函数
- 《设计模式》(GoF) - 23种设计模式
- 《嵌入式实时操作系统μC/OS-III》 - RTOS原理

**在线课程**:
- MIT 6.S081 操作系统工程
- 清华大学 操作系统 (学堂在线)
- B站 王道考研 - 操作系统

**实践**:
- FreeRTOS 官方文档和示例
- Crazyflie 源码: https://github.com/bitcraze/crazyflie-firmware
- LeetCode 多线程题目

---

## 附录: 关键概念速查表

| 概念 | 一句话解释 | ESP-Drone 应用 |
| --- | --- | --- |
| **生产者-消费者** | 通过缓冲区解耦生产和消费 | workerQueue |
| **命令模式** | 将请求封装为对象 | worker_work 结构体 |
| **多态** | 同一接口，不同实现 | 函数指针回调 |
| **线程池** | 预创建线程，重复利用 | workerLoop (简化版) |
| **优先级调度** | 高优先级任务优先执行 | FreeRTOS 任务优先级 |
| **信号量** | 资源计数/事件通知 | canStartMutex |
| **互斥锁** | 保护共享资源 | I2C 总线访问 |
| **队列** | 任务间通信 | workerQueue, setpointQueue |
| **卡尔曼滤波** | 传感器数据融合 | estimator_kalman.c |
| **PID控制** | 反馈控制算法 | controller_pid.c |

---

## 总结

ESP-Drone 是一个融合多种设计模式和系统架构思想的优秀嵌入式项目:

1. **实时性**: 通过 FreeRTOS 优先级调度保证 1000Hz 控制循环
2. **可靠性**: 静态内存分配、优先级设计、安全机制
3. **可扩展性**: 模块化设计、分层架构、驱动抽象
4. **高效性**: 双核 SMP、异步任务、队列通信

通过学习这个项目，可以深入理解操作系统、嵌入式系统、控制理论的实际应用。

---

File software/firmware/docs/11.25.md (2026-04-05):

# 2025-11-25

## 本次汇报概要

- 解决上周的传感器模块的一些问题。
- 飞控的主要任务和任务分配。

## 上周遗留问题
### IMU数据处理的流程

#### 1.陀螺仪校准过程

由于陀螺仪存在较大的误差，包括零漂和温漂，因此每次使用前需要对陀螺仪进行校准，计算当前环境下的陀螺仪基准值：**在初次上电时，计算陀螺仪三个轴的方差与平均值。**

陀螺仪具体校准过程如下：

使用一个最大长度为 1024 的环形缓冲区，存储最新的 1024 组陀螺仪测量值。

通过计算陀螺仪输出值方差，确认飞行器已经放置平稳并且陀螺仪工作正常。

确认第 2 步正常后，计算静止时 1024 组陀螺仪输出值的平均值，作为陀螺仪的校准值。

代码如下：

```c
static void sensorsAddBiasValue(BiasObj *bias, int16_t x, int16_t y, int16_t z)
{
    bias->bufHead->x = x;
    bias->bufHead->y = y;
    bias->bufHead->z = z;
    bias->bufHead++;

    if (bias->bufHead >= &bias->buffer[SENSORS_NBR_OF_BIAS_SAMPLES])
    {
        bias->bufHead = bias->buffer;
        bias->isBufferFilled = true;
    }
}

static bool sensorsFindBiasValue(BiasObj *bias)
{
    static int32_t varianceSampleTime;
    bool foundBias = false;

    if (bias->isBufferFilled)
    {
        sensorsCalculateVarianceAndMean(bias, &bias->variance, &bias->mean);

        if (bias->variance.x < GYRO_VARIANCE_THRESHOLD_X &&
            bias->variance.y < GYRO_VARIANCE_THRESHOLD_Y &&
            bias->variance.z < GYRO_VARIANCE_THRESHOLD_Z &&
            (varianceSampleTime + GYRO_MIN_BIAS_TIMEOUT_MS < xTaskGetTickCount()))
        {
            varianceSampleTime = xTaskGetTickCount();
            bias->bias.x = bias->mean.x;
            bias->bias.y = bias->mean.y;
            bias->bias.z = bias->mean.z;
            foundBias = true;
            bias->isBiasValueFound = true;
        }
    }

    return foundBias;
}
```

#### 加速度计校准过程
做重力加速度校准

在地球不同的纬度和海拔下，重力加速度 g 值一般不同，因此需要使用加速度计对 g 进行实际测量。
g 值的校准过程如下：

陀螺仪校准完成后，立刻进行加速度计校准。

使用 Buffer 保存 200 组加速度计测量值。

通过合成重力加速度在三个轴的分量，计算重力加速度在静止状态下的值。

计算静止状态下重力加速度值

代码如下:

```c
static bool processAccScale(int16_t ax, int16_t ay, int16_t az)
{
    if (!accScaleFound)
    {
        accScaleSum += sqrtf(powf(ax * SENSORS_BMI088_G_PER_LSB_CFG, 2) +
                             powf(ay * SENSORS_BMI088_G_PER_LSB_CFG, 2) +
                             powf(az * SENSORS_BMI088_G_PER_LSB_CFG, 2));
        accScaleSumCount++;

        if (accScaleSumCount == SENSORS_ACC_SCALE_SAMPLES)
        {
            accScale = accScaleSum / SENSORS_ACC_SCALE_SAMPLES;
            accScaleFound = true;
        }
    }

    return accScaleFound;
}
```

#### 滤波器处理输出数据
在经过陀螺仪校准和加速度计校准后，加入修正，再通过低通滤波器过滤高频噪音，最后作为输入控制系统的数据

代码如下:

```c
// 陀螺仪数据处理
sensorData.gyro.x = (gyroRaw.x - gyroBias.x) * SENSORS_BMI088_DEG_PER_LSB_CFG;
sensorData.gyro.y = (gyroRaw.y - gyroBias.y) * SENSORS_BMI088_DEG_PER_LSB_CFG;
sensorData.gyro.z = (gyroRaw.z - gyroBias.z) * SENSORS_BMI088_DEG_PER_LSB_CFG;
applyAxis3fLpf((lpf2pData *)(&gyroLpf), &sensorData.gyro);

// 加速度计数据处理
accScaled.x = accelRaw.x * SENSORS_BMI088_G_PER_LSB_CFG / accScale;
accScaled.y = accelRaw.y * SENSORS_BMI088_G_PER_LSB_CFG / accScale;
accScaled.z = accelRaw.z * SENSORS_BMI088_G_PER_LSB_CFG / accScale;
sensorsAccAlignToGravity(&accScaled, &sensorData.acc);
applyAxis3fLpf((lpf2pData *)(&accLpf), &sensorData.acc);
```

其中低通滤波函数 `applyAxis3fLpf` 的实现：

```c
static void applyAxis3fLpf(lpf2pData *data, Axis3f *in)
{
    for (uint8_t i = 0; i < 3; i++)
    {
        in->axis[i] = lpf2pApply(&data[i], in->axis[i]);
    }
}
```

#### 机身水平校准
理想状态下，加速度传感器在小飞机上完全水平地进行安装，进而可以使用 0 位置作为小飞机的水平面。但由于加速度计在安装时不可避免的存在一定的倾角，导致飞控系统错误估计水平位置，导致小飞机向某个方向偏飞。因此需要设置一定的校准策略来平衡这种误差。

将小飞机放置在一个水平面上，计算小飞机 cosRoll、sinRoll、cosPitch、sinPitch。理想状态下 cosRoll、cosPitch 为 1，sinPitch、sinRoll 为 0。如果不是水平安装 sinPitch、sinRoll 不为 0，cosRoll cosPitch 不为 1。

将步骤 1 的 cosRoll、sinRoll、cosPitch、sinPitch 或对应的 Roll、Pitch 角度值保存到飞机，用于校准。

利用校准值，对加速度计测量值进行修正：

代码如下：

```c
static void sensorsAccAlignToGravity(Axis3f *in, Axis3f *out)
{
    Axis3f rx;
    Axis3f ry;

    // Rotate around x-axis
    rx.x = in->x;
    rx.y = in->y * cosRoll - in->z * sinRoll;
    rx.z = in->y * sinRoll + in->z * cosRoll;

    // Rotate around y-axis
    ry.x = rx.x * cosPitch - rx.z * sinPitch;
    ry.y = rx.y;
    ry.z = -rx.x * sinPitch + rx.z * cosPitch;

    out->x = ry.x;
    out->y = ry.y;
    out->z = ry.z;
}
```

## 本周工作
### 飞控系统的主要任务
Crazyflie 是基于 FreeRTOS，所有 FreeRTOS 的任务设置可在 **components\config\include\config.h** 文件修改

#### 任务优先级分配（数字越大优先级越高）

系统按功能模块划分为以下几类任务，优先级从低到高：

##### 1. 系统状态管理任务（优先级 1）
- **SYSTEM_TASK** (优先级 1)：系统初始化与状态管理
- **PM_TASK** (优先级 1)：电源管理任务 实际用不上
- **LEDSEQCMD_TASK** (优先级 1)：LED 灯控制 实际是控制led灯闪烁表示信息
- **KALMAN_TASK** (优先级 4，单核时降为 1)：卡尔曼滤波状态估计 重要

##### 2. 通信任务（优先级 2）
**发送任务 (TX)：**
- **UDP_TX_TASK** (优先级 2)：UDP 数据发送
- **CRTP_TX_TASK** (优先级 2)：CRTP 协议数据发送

**接收任务 (RX)：**
- **UDP_RX_TASK** (优先级 2)：UDP 数据接收
- **EXTRX_TASK** (优先级 2)：外部接收器任务
- **UART2_TASK** (优先级 2)：UART2 串口通信 目前没用，之后考虑接入SUBS协议兼容实物遥控器
- **SYSLINK_TASK** (优先级 2)：系统链路通信 目前没用，被WiFi代替了
- **USBLINK_TASK** (优先级 2)：USB 链路通信 没用
- **WIFILINK_TASK** (优先级 2)：Wi-Fi 链路通信 重要,通信的底层实现
- **CRTP_RX_TASK** (优先级 2)：CRTP 协议数据接收

**数据处理任务 (优先级 2-3)：**
- **INFO_TASK** (优先级 2)：信息管理 没有用
- **LOG_TASK** (优先级 2)：日志记录 
- **MEM_TASK** (优先级 2)：内存管理
- **PARAM_TASK** (优先级 2)：参数管理
- **CMD_HIGH_LEVEL_TASK** (优先级 3)：高层命令处理

##### 3. 传感器与稳定控制任务（优先级 4-7，最高优先级）
- **PROXIMITY_TASK** (优先级 5)：距离传感器任务 没有用
- **FLOW_TASK** (优先级 5)：光流传感器任务
- **ZRANGER2_TASK** (优先级 5)：Z-Ranger2 测距任务
- **ZRANGER_TASK** (优先级 5)：Z-Ranger 测距任务
- **SENSORS_TASK** (优先级 6)：传感器数据采集与处理
- **STABILIZER_TASK** (优先级 7)：**最高优先级**，飞控核心稳定控制循环

#### 任务堆栈分配（单位：configBASE_STACK_SIZE 的倍数）

`configBASE_STACK_SIZE` 由 `CONFIG_BASE_STACK_SIZE` 配置决定。

| 任务名称 | 堆栈大小 | 说明 |
| --- | --- | --- |
| SYSTEM_TASK | 6× | 系统初始化需要较大堆栈 |
| SENSORS_TASK | 5× | 传感器数据处理 |
| STABILIZER_TASK | 5× | 稳定控制算法 |
| PM_TASK | 4× | 电源管理 |
| UDP_RX_TASK | 4× | UDP 接收缓冲 |
| UDP_TX_TASK | 4× | UDP 发送缓冲 |
| WIFILINK_TASK | 4× | Wi-Fi 通信 |
| ZRANGER2_TASK | 4× | 测距传感器2 |
| CRTP_RX_TASK | 3× | CRTP 接收 |
| CRTP_TX_TASK | 3× | CRTP 发送 |
| FLOW_TASK | 3× | 光流计算 |
| KALMAN_TASK | 3× | 卡尔曼滤波计算 |
| LOG_TASK | 3× | 日志处理 |
| CMD_HIGH_LEVEL_TASK | 2× | 高层命令 |
| LEDSEQCMD_TASK | 2× | LED 控制闪烁 |
| MEM_TASK | 2× | 内存管理 |
| PARAM_TASK | 2× | 参数管理 |
| ZRANGER_TASK | 2× | 测距传感器1 |
| EXTRX_TASK | 1× | 外部接收 |
| SYSLINK_TASK | 1× | 系统链路 |
| UART2_TASK | 1× | 串口通信 |
| USBLINK_TASK | 1× | USB 链路 |

#### 核心任务功能分析

##### STABILIZER_TASK（优先级 7，最高）
- **功能**：1000Hz 飞控核心循环，负责读取传感器 → 状态估计 → PID 控制 → 电机输出
- **重要性**：整个飞控系统的心脏，必须以最高优先级运行保证实时性
- **堆栈**：5× 基准堆栈，用于控制算法计算

##### SENSORS_TASK（优先级 6）
- **功能**：从 IMU、气压计等传感器读取原始数据，进行校准、滤波处理
- **数据流**：硬件中断 → 读取原始数据 → 校准 → 低通滤波 → 传递给 STABILIZER_TASK
- **堆栈**：5× 基准堆栈，用于传感器数据处理与滤波

##### KALMAN_TASK（优先级 4，单核降为 1）
- **功能**：卡尔曼滤波器状态估计，融合多传感器数据（IMU、气压计、光流等）
- **特殊处理**：在单核系统中优先级降为 1，因为卡尔曼滤波计算量大，避免阻塞其他关键任务
- **堆栈**：3× 基准堆栈

##### 通信任务（优先级 2）
- **WIFILINK_TASK / UDP_RX_TASK / UDP_TX_TASK**：处理 Wi-Fi/UDP 通信，接收控制指令、发送遥测数据
- **CRTP_RX_TASK / CRTP_TX_TASK**：Crazy RealTime Protocol，与 Crazyflie 客户端通信的核心协议
- **堆栈分配**：通信任务分配较大堆栈（3-4×）用于网络缓冲区

##### 系统管理任务（优先级 1-2）
- **PARAM_TASK / LOG_TASK**：参数调整与日志记录，支持运行时参数调优和遥测
- **PM_TASK**：电池电压监控、低电压保护

#### 优先级设计原则总结

1. **实时控制最高优先级**（6-7）：STABILIZER 和 SENSORS 确保 1000Hz 控制循环不被打断
2. **传感器融合次高优先级**（4-5）：光流、测距等辅助传感器
3. **通信与数据处理中等优先级**（2-3）：保证指令及时响应，但不影响飞控稳定
4. **系统管理最低优先级**（1）：LED、电源管理等非实时任务

**注意事项**：
- 单核系统（`CONFIG_FREERTOS_UNICORE`）会将卡尔曼任务优先级降为 1，避免 CPU 占用过高
- FreeRTOS 配置要求 `CONFIG_FREERTOS_HZ=1000`（1ms tick）以支持精确的 1000Hz 控制

#### ESP32 适应措施

`config.h` 文件也被修改来针对 ESP32 适配

##### 1. 硬件平台检测与验证
```c
#ifdef CONFIG_TARGET_ESPLANE_V2_S2
#ifndef CONFIG_IDF_TARGET_ESP32S2
#error "ESPLANE_V2 hardware with ESP32S2 onboard"
#endif
#elif defined(CONFIG_TARGET_ESPLANE_V1)
#ifndef CONFIG_IDF_TARGET_ESP32
#error "ESPLANE_V1 hardware with ESP32 onboard"
#endif
#elif defined(CONFIG_TARGET_ESP32_S2_DRONE_V1_2)
#ifdef CONFIG_IDF_TARGET_ESP32
#error "ESP32_S2_DRONE_V1_2 hardware with ESP32S2/S3 onboard"
#endif
#endif
```
**作用**：编译时检查硬件配置与芯片型号是否匹配，防止配置错误导致硬件损坏或功能异常。

没啥作用，以后删除

##### 2. 单核/双核 CPU 适配
```c
// the kalman filter consumes a lot of CPU
// for single core systems, we need to lower the priority
#if CONFIG_FREERTOS_UNICORE
  #undef KALMAN_TASK_PRI
  #define KALMAN_TASK_PRI         1
#endif
```
**作用**：
- ESP32 单核模式下，卡尔曼滤波优先级从 4 降为 1
- 避免计算密集型任务阻塞飞控核心循环（STABILIZER_TASK 优先级 7）

这个表示单核情况下可能不用卡尔曼做数据融合，姿态解算

##### 3. ESP-IDF 配置系统集成
```c
#include "usec_time.h"
#include "sdkconfig.h"
```
**作用**：
- `sdkconfig.h`：引入 ESP-IDF 的 Kconfig 配置系统
- 使用 `CONFIG_FREERTOS_UNICORE`、`CONFIG_BASE_STACK_SIZE` 等动态配置
- 替代原 STM32 固件的硬编码方式

##### 4. 动态堆栈大小配置
```c
#define configBASE_STACK_SIZE CONFIG_BASE_STACK_SIZE
```
**作用**：
- 使用 menuconfig 中的 `CONFIG_BASE_STACK_SIZE` 而非硬编码
- 根据 ESP32/S2/S3 不同内存容量动态调整堆栈

##### 5. STM32 配置隔离
```c
#ifdef STM32F4XX 
  #define CONFIG_BLOCK_ADDRESS    (2048 * (64-1))
  // ... STM32 特定配置
  #define FREERTOS_MCU_CLOCK_HZ   168000000
#endif
```
**作用**：
- STM32 相关配置被条件编译隔离
- ESP32 不使用这些定义（内存地址、时钟频率等由 ESP-IDF 管理）
- 保持代码兼容性同时避免冲突

可以删除

##### 可选功能开关说明

`config.h` 中有大量被注释的宏定义，它们是**可选功能开关**，默认禁用以保持固件稳定和高效：

##### 功能特性开关（默认关闭）

**ACTIVATE_AUTO_SHUTDOWN**
```c
//#define ACTIVATE_AUTO_SHUTDOWN
```
- **功能**：无线电信号丢失时自动关机
- 在特定测试场景需要

**ACTIVATE_STARTUP_SOUND**
```c
//#define ACTIVATE_STARTUP_SOUND
```
- **功能**：启动时电机播放旋律（通过 PWM 调制）

**FORCE_EXP_DETECT**
```c
//#define FORCE_EXP_DETECT
```
- **功能**：强制初始化扩展板驱动（测试台用）
- 正常飞行无扩展板

##### 调试功能开关（生产环境禁用）

**PRINT_OS_DEBUG_INFO**
```c
//#define PRINT_OS_DEBUG_INFO
```
- **功能**：定期打印 FreeRTOS 内存/堆栈使用信息
- DEBUG时使用，同时DEBUG功能被ESP_LOG功能替代

**ADC_OUTPUT_RAW_DATA**
```c
//#define ADC_OUTPUT_RAW_DATA
```
- **功能**：将陀螺仪原始数据输出到 UART（需 2Mbps 高速串口）
- 传感器校准或数据分析时启用，平时用不到

**BRUSHLESS_MOTORCONTROLLER**
```c
//#define BRUSHLESS_MOTORCONTROLLER
```
- **功能**：启用无刷电调支持（需 DSHOT 协议）
- ESP_DRONE没有实现这个，可以删了

**MOTOR_RAMPUP_TEST**
```c
//#define MOTOR_RAMPUP_TEST
```
- **功能**：电机斜坡测试
- ESP_DRONE没有实现这个，可以删了

##### 安全保护机制

文件底部的编译检查防止误启用冲突功能：
```c
#if defined(UART_OUTPUT_TRACE_DATA) && defined(ADC_OUTPUT_RAW_DATA)
#  error "Can't define UART_OUTPUT_TRACE_DATA and ADC_OUTPUT_RAW_DATA at the same time"
#endif
```

## 下周计划
分析修改 stabilizerTask 
分析system.c

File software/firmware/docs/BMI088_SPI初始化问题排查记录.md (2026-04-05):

# BMI088 SPI 初始化问题完整排查记录

**日期**: 2025年12月21日  
**硬件**: ESP32-S3-WROOM-1 + BMI088 IMU  
**ESP-IDF**: v5.5.1  
**问题**: ESP-Drone 平台配置为 EP30 后系统测试失败

---

## 问题发现

### 初始症状
平台字符串修改为 `"0;EP30"` 后，系统启动日志显示核心测试失败：

```
I (9864) SYS: stabilizerTest = 0          ❌ 稳定控制器测试失败
I (9864) SYS: estimatorKalmanTaskTest = 0  ❌ 卡尔曼滤波器测试失败
```

**分析**: EP30 平台配置要求使用 BMI088 传感器（`SensorImplementation_bmi088_spi_ms5611`），上述测试失败表明传感器初始化存在问题。

### 错误日志
```
I (3332) BMI088_SPI: ACC Chip ID: 0x1E (expected: 0x1E)  ✅ 加速度计正常
I (3348) BMI088_SPI: GYRO Chip ID: 0xFF (expected: 0x0F)  ❌ 陀螺仪失败
E (3352) BMI088_SPI: Invalid gyroscope chip ID
E (3352) BMI088: BMI088 initialization failed             ❌ 初始化中止
```

**结论**: BMI088 传感器部分工作（加速度计正常），部分失败（陀螺仪返回 0xFF），导致整个系统初始化失败。

---

## 排查流程（按时间顺序）

### 第一步：初步诊断 - SPI 通信测试

#### 诊断方法
在 `bmi088_spi_check_chip_id()` 添加多寄存器读取测试：

```c
// 测试陀螺仪多个寄存器
uint8_t test_data[3];
bmi088_gyro_read_reg(dev, 0x00, &test_data[0], 1);  // Chip ID 寄存器
bmi088_gyro_read_reg(dev, 0x0F, &test_data[1], 1);  // 另一个已知寄存器
bmi088_gyro_read_reg(dev, 0x10, &test_data[2], 1);  // 第三个寄存器

ESP_LOGI(TAG, "GYRO test reads: reg 0x00=0x%02X, reg 0x0F=0x%02X, reg 0x10=0x%02X", 
         test_data[0], test_data[1], test_data[2]);
```

#### 测试结果
```
I (3350) BMI088_SPI: GYRO test reads: reg 0x00=0xFF, reg 0x0F=0xFF, reg 0x10=0xFF
```

**关键发现**: 所有寄存器读取都返回 0xFF，这是 SPI MISO 线浮空的典型表现！

#### 初步结论
- ✅ 加速度计工作正常 → SPI 总线（MISO/MOSI/CLK）本身没问题
- ❌ 陀螺仪完全无响应 → 问题聚焦在陀螺仪的片选信号（CS1）

---

### 第二步：逻辑死锁问题 - "先有鸡还是先有蛋"

#### 问题现象
尝试初始化 BMI088 时，发现无法读取芯片 ID，但读取函数本身没有返回错误。

#### 原因分析
检查 `bmi088_spi.c` 的读写函数，发现存在 `is_initialized` 标志检查：

```c
// 原代码（错误版本）
bool bmi088_acc_read_reg(bmi088_dev_t *dev, uint8_t reg_addr, uint8_t *data, size_t length)
{
    if (!dev->is_initialized) {  // ❌❌❌ 逻辑死锁！
        ESP_LOGE(TAG, "Device not initialized");
        return false;
    }
    
    // ... SPI 传输代码 ...
}

bool bmi088_spi_init(bmi088_dev_t *dev)
{
    // 初始化 SPI 总线...
    
    // 需要读取芯片 ID 来验证通信
    if (!bmi088_spi_check_chip_id(dev)) {  // 调用 bmi088_acc_read_reg()
        return false;
    }
    
    // 只有验证成功后才设置标志
    dev->is_initialized = true;  // ⚠️ 但是读取函数要求先设置这个标志！
    return true;
}
```

#### 发现问题 1：循环依赖（经典死锁）

**问题本质**：这是一个经典的"先有鸡还是先有蛋"类型的逻辑错误：

```
初始化流程：
1. 调用 bmi088_spi_init()
2. 需要调用 bmi088_spi_check_chip_id() 验证芯片
3. bmi088_spi_check_chip_id() 调用 bmi088_acc_read_reg() 读取寄存器
4. bmi088_acc_read_reg() 检查 is_initialized 标志
5. is_initialized == false → 返回错误
6. 芯片 ID 验证失败
7. is_initialized 永远无法被设置为 true
8. 死锁！
```

**根本矛盾**：
- 读取函数要求 `is_initialized == true` 才能工作
- `is_initialized` 只有在芯片 ID 验证成功后才会设置为 `true`
- 但芯片 ID 验证需要调用读取函数
- **循环依赖，永远无法完成初始化！**

#### 修复方案
**文件**: `components/drivers/spi_devices/bmi088/bmi088_spi.c`  
**位置**: Lines 168-220

```c
// ✅ 修复后：移除 is_initialized 检查
bool bmi088_acc_read_reg(bmi088_dev_t *dev, uint8_t reg_addr, uint8_t *data, size_t length)
{
    if (dev == NULL || data == NULL || length == 0) {
        return false;
    }
    // ✅ 不再检查 is_initialized，允许在初始化期间读取寄存器
    
    uint8_t tx_buf[length + 2];
    uint8_t rx_buf[length + 2];
    // ... SPI 传输代码 ...
}

bool bmi088_gyro_read_reg(bmi088_dev_t *dev, uint8_t reg_addr, uint8_t *data, size_t length)
{
    if (dev == NULL || data == NULL || length == 0) {
        return false;
    }
    // ✅ 同样移除 is_initialized 检查
    
    uint8_t tx_buf[length + 1];
    uint8_t rx_buf[length + 1];
    // ... SPI 传输代码 ...
}
```

**修复原理**：
- 读写函数只检查参数有效性，不检查初始化状态
- 允许在初始化过程中调用读写函数
- 初始化函数负责确保 SPI 总线已正确配置
- 避免循环依赖，让初始化流程可以正常完成

**经验教训**：
- ❌ **错误的防御性编程**：过度使用状态检查可能导致逻辑死锁
- ✅ **正确的做法**：在调用者层面保证顺序，底层函数保持简单
- 🔑 **关键原则**：如果函数 A 在初始化时需要调用函数 B，那么函数 B 不能要求初始化已完成

---

### 第三步：SPI 总线配置检查

#### 检查 SPI 引脚配置
在 `spi_drv.c` 添加诊断日志：

```c
ESP_LOGI(TAG, "SPI Bus Init - MISO: %d, MOSI: %d, CLK: %d",
         bus_config->pin_config.miso_pin,
         bus_config->pin_config.mosi_pin,
         bus_config->pin_config.sclk_pin);

ESP_LOGI(TAG, "SPI Device - CS: %d, Freq: %d Hz, Mode: %d",
         device_config->cs_pin,
         device_config->clock_speed_hz,
         device_config->mode);
```

#### 日志输出
```
I (3115) SPI_DRV: SPI Bus Init - MISO: 13, MOSI: 11, CLK: 12  ✅
I (3117) BMI088_CFG: ACC CS: 10, GYRO CS: 9, Freq: 10000000 Hz
```

**初步排查**: SPI 总线引脚正确，加速度计 CS=10，陀螺仪 CS=9。

#### 发现问题 2：SPI 工作模式配置错误

继续检查 SPI 总线配置，在 `spi_drv.c` 的设备配置代码中发现：

```c
// components/drivers/spi_bus/spi_drv.c:343
spi_device_interface_config_t device_cfg = {
    .clock_speed_hz = device_config->clock_speed_hz,
    .mode = device_config->mode,
    .spics_io_num = -1,
    .queue_size = device_config->queue_size,
    .flags = SPI_DEVICE_HALFDUPLEX,  // ❌❌❌ 半双工模式！
    // ...
};
```

**问题分析**：

**半双工 vs 全双工的区别**：
- **半双工（Half-Duplex）**: MOSI 和 MISO 不能同时工作
  - 发送阶段：只使用 MOSI，MISO 被忽略
  - 接收阶段：只使用 MISO，MOSI 发送 dummy 数据
  - 适用于只读或只写的传感器

- **全双工（Full-Duplex）**: MOSI 和 MISO 同时工作
  - 发送地址的同时接收数据
  - 适用于大多数标准 SPI 传感器

**BMI088 的要求**：
- BMI088 在读取操作时，需要**同时发送**读地址并**接收**回显和数据
- 读取过程：
  ```
  MOSI: [读地址] [0x00] [0x00]  ← 持续发送
  MISO: [地址回显] [虚拟字节] [数据]  ← 同时接收
  ```
- 如果使用半双工模式，发送地址后 MISO 数据会被丢弃！

**症状**：
- 半双工模式下，发送阶段完成后才开始接收
- 导致接收到的数据与时序不匹配
- 可能读取到全 0x00 或全 0xFF

**修复**:
```c
// components/drivers/spi_bus/spi_drv.c:343
spi_device_interface_config_t device_cfg = {
    .clock_speed_hz = device_config->clock_speed_hz,
    .mode = device_config->mode,
    .spics_io_num = -1,  // 手动管理 CS
    .queue_size = device_config->queue_size,
    .flags = 0,  // ✅✅✅ 全双工模式（去掉 SPI_DEVICE_HALFDUPLEX）
    .pre_cb = NULL,
    .post_cb = NULL
};
```

**验证方法**：
修改后重新编译，观察日志中是否能正确读取芯片 ID。如果仍然失败，说明还有其他问题。

---

### 第四步：BMI088 加速度计协议分析

#### 问题现象
修改为全双工模式后重新测试，发现**第一次读取**加速度计芯片 ID 返回 0x00，第二次才正常。

#### 原因分析
查阅 BMI088 数据手册 Section 5.2.1：
> The first data byte of accelerometer returned by read operation is a dummy byte

BMI088 加速度计的 SPI 协议特殊性：
1. 发送：`[读地址]`
2. 接收：`[地址回显, 虚拟字节, 真实数据]`

#### 发现问题 3：数据提取位置错误
原代码：
```c
// bmi088_spi.c
uint8_t rx_buf[length + 2];
// ...传输...
memcpy(data, &rx_buf[1], length);  // ❌ 从 rx_buf[1] 开始提取
```

实际 rx_buf 内容（读取 Chip ID 示例）：
```
rx_buf[0] = 0xFF  // 地址回显（读操作时为 0xFF）
rx_buf[1] = 0x00  // 虚拟字节
rx_buf[2] = 0x1E  // 真实的芯片 ID
```

**修复**:
```c
// components/drivers/spi_devices/bmi088/bmi088_spi.c:199
// 从第三个字节开始提取（跳过地址回显和虚拟字节）
memcpy(data, &rx_buf[2], length);  // ✅
```

#### 发现问题 4：缺少虚拟读取
即使修正了数据提取位置，第一次读取仍返回无效数据。

**解决方案**: 添加虚拟读取逻辑
```c
// components/drivers/spi_devices/bmi088/bmi088_spi.c:416-450
bool bmi088_spi_check_chip_id(bmi088_dev_t *dev)
{
    uint8_t acc_chip_id, dummy;
    
    // 第一次读取（虚拟，丢弃结果）
    bmi088_acc_read_reg(dev, BMI088_ACC_CHIP_ID_REG, &dummy, 1);
    BMI088_DELAY_MS(10);
    
    // 第二次读取（真实数据）
    bmi088_acc_read_reg(dev, BMI088_ACC_CHIP_ID_REG, &acc_chip_id, 1);
    
    ESP_LOGI(TAG, "ACC Chip ID: 0x%02X (expected: 0x%02X)", 
             acc_chip_id, BMI088_ACC_CHIP_ID);
    
    return (acc_chip_id == BMI088_ACC_CHIP_ID);
}
```

**测试结果**: 加速度计芯片 ID 现在稳定读取为 0x1E ✅

---

### 第五步：陀螺仪仍然失败 - GPIO 冲突排查

#### 现状
- 加速度计问题全部解决，稳定读取 0x1E
- 陀螺仪仍然返回 0xFF

#### 深入检查 Kconfig 配置
打开 `main/Kconfig.projbuild`，逐行检查所有 GPIO 分配：

```kconfig
# SPI 配置
config SPI_PIN_MISO
    default 13  # ✅ HSPI 推荐引脚

config SPI_PIN_MOSI
    default 11  # ⚠️ 注意这个引脚

config SPI_PIN_CLK
    default 12  # ✅

config SPI_PIN_CS0
    default 10  # ✅ 加速度计 CS

config SPI_PIN_CS1
    default 9   # ⚠️ 陀螺仪 CS，需要检查是否被占用

# I2C0 配置（用于其他传感器）
config I2C0_PIN_SDA
    default 11  # ❌ 冲突！与 SPI_MOSI 相同

config I2C0_PIN_SCL
    default 10  # ❌ 冲突！与 SPI_CS0 相同

# LED 配置
config LED_PIN_BLUE
    default 7   # ✅

config LED_PIN_GREEN
    default 9   # ❌❌❌ 关键冲突！与 SPI_CS1 相同

config LED_PIN_RED
    default 8   # ✅

# 蜂鸣器配置
config BUZ1_PIN_POS
    default 39  # ⚠️

config BUZ2_PIN_NEG
    default 38  # ⚠️

# I2C1 配置
config I2C1_PIN_SDA
    default 40  # ⚠️

config I2C1_PIN_SCL
    default 41  # ⚠️
```

#### 发现问题 4：GPIO 9 被 LED_GREEN 占用！

**根本原因**: GPIO 9 同时分配给了：
1. `SPI_PIN_CS1` (陀螺仪片选)
2. `LED_PIN_GREEN` (绿色 LED)

这导致陀螺仪 CS 信号无法正常工作，GPIO 9 实际被 LED 驱动占用！

#### ESP32-S3 GPIO 限制分析
参考 ESP32-S3-WROOM-1 数据手册：
- **GPIO 26-37**: 被 Flash/PSRAM 占用（**绝对不可用**）
- **GPIO 19-20**: USB D-/D+（尽量避免）
- **GPIO 0, 3, 45, 46**: Strapping pins（谨慎使用）
- **可用 GPIO**: 1-18, 21, 38-48（除去上述限制）

---

### 第五步：系统性 GPIO 重分配

#### 重分配策略
1. **优先保证 SPI**: 使用推荐的 HSPI 引脚（10-13）
2. **I2C 远离 SPI**: 移到 38-41 区域
3. **LED 和蜂鸣器**: 使用剩余的低编号 GPIO

#### 新的 GPIO 分配方案

| 功能 | 原 GPIO | 新 GPIO | 修改原因 |
| --- | --- | --- | --- |
| SPI_MISO | 13 | 13 | ✅ 保持不变（HSPI 推荐）  |
| SPI_MOSI | 11 | 11 | ✅ 保持不变（HSPI 推荐）  |
| SPI_CLK | 12 | 12 | ✅ 保持不变（HSPI 推荐）  |
| SPI_CS0 (ACC) | 10 | 10 | ✅ 保持不变（HSPI 推荐）  |
| **SPI_CS1 (GYRO)** | **9** | **16**  | ❌❌ 解决与 LED_GREEN 冲突 |
| **I2C0_SDA** | **11**  | **41**  | ❌ 解决与 SPI_MOSI 冲突 |
| **I2C0_SCL** | **10**  | **40**  | ❌ 解决与 SPI_CS0 冲突 |
| LED_BLUE | 7 | 7 | ✅ 保持不变 |
| **LED_GREEN** | **9** | **17**  | ❌ 释放 GPIO 9 给 SPI_CS1 |
| LED_RED | 8 | 8 | ✅ 保持不变 |
| **BUZ1_PIN_POS** | **39**  | **21**  | ⚠️ 避免与 I2C1 接近 |
| **BUZ2_PIN_NEG** | **38**  | **48**  | ⚠️ 避免与 I2C1 接近 |
| **I2C1_SDA** | **40**  | **38**  | ⚠️ 与蜂鸣器分开 |
| **I2C1_SCL** | **41**  | **39**  | ⚠️ 与蜂鸣器分开 |
| BMI088_INT1 (ACC)  | 15 | 15 | ✅ 保持不变 |
| BMI088_INT3 (GYRO) | 14 | 14 | ✅ 保持不变 |

#### 修改 Kconfig
```kconfig
# main/Kconfig.projbuild

menu "sensors config"
    config SPI_PIN_CS1
        int "SPI_PIN_CS1 GPIO number"
        range 0 48
        default 16  # 从 9 改为 16 ✅
        help
            GPIO number (IOxx) SPI_PIN_CS1 (BMI088 Gyroscope)
    
    config I2C0_PIN_SDA
        int "I2C0_PIN_SDA GPIO number"
        default 41  # 从 11 改为 41 ✅
    
    config I2C0_PIN_SCL
        int "I2C0_PIN_SCL GPIO number"
        default 40  # 从 10 改为 40 ✅
    
    config I2C1_PIN_SDA
        int "I2C1_PIN_SDA GPIO number"
        default 38  # 从 40 改为 38 ✅
    
    config I2C1_PIN_SCL
        int "I2C1_PIN_SCL GPIO number"
        default 39  # 从 41 改为 39 ✅
endmenu

menu "led config"
    config LED_PIN_GREEN
        int "LED_PIN_GREEN GPIO number"
        default 17  # 从 9 改为 17 ✅
endmenu

menu "buzzer"
    config BUZ1_PIN_POS
        int "BUZ1_PIN_POS GPIO number"
        default 21  # 从 39 改为 21 ✅
    
    config BUZ2_PIN_NEG
        int "BUZ2_PIN_NEG GPIO number"
        default 48  # 从 38 改为 48 ✅
endmenu
```

#### 配置更新流程（关键步骤）
```powershell
# 1. 删除旧的配置文件（必须！否则 Kconfig 修改不生效）
rm sdkconfig

# 2. 重新生成配置
idf.py menuconfig
# 检查：ESPDrone Config → sensors config → SPI_PIN_CS1 = 16

# 3. 完全清理并重新编译
idf.py fullclean
idf.py build

# 4. 烧录并查看日志
idf.py -p COM3 flash monitor
```

---

### 第六步：测试结果 - 部分成功

#### 日志输出
```
I (3117) BMI088_CFG: ACC CS: 10, GYRO CS: 16, Freq: 10000000 Hz  ✅ CS 引脚正确
I (3327) BMI088_SPI: ACC Chip ID: 0x1E (expected: 0x1E)         ✅ 加速度计成功
I (3379) BMI088_SPI: GYRO Chip ID: 0x0F (expected: 0x0F)        ✅ 陀螺仪成功！
I (3384) BMI088_SPI: BMI088 chip ID verification passed         ✅
```

**重大突破**: GPIO 重分配后，陀螺仪芯片 ID 读取成功！

#### 但是...新问题出现
```
E (3527) BMI088_SPI: Power mode configuration failed  ❌
E (3527) BMI088: BMI088 initialization failed
```

芯片 ID 验证通过，但后续的电源模式配置失败。

---

### 第七步：陀螺仪软复位时序问题

#### 分析流程
1. 芯片 ID 读取成功 → SPI 通信正常
2. 电源模式配置失败 → 可能是初始化时序问题

#### 检查软复位代码
```c
// components/drivers/spi_devices/bmi088/bmi088_spi.c
bool bmi088_spi_soft_reset(bmi088_dev_t *dev)
{
    // 加速度计复位
    uint8_t acc_reset_cmd = 0xB6;
    bmi088_acc_write_reg(dev, BMI088_ACC_SOFTRESET_REG, &acc_reset_cmd, 1);
    BMI088_DELAY_MS(1);  // ⚠️ 原延迟 1ms
    
    // 陀螺仪复位
    uint8_t gyro_reset_cmd = 0xB6;
    bmi088_gyro_write_reg(dev, BMI088_GYRO_SOFTRESET_REG, &gyro_reset_cmd, 1);
    BMI088_DELAY_MS(1);  // ⚠️ 原延迟 1ms
    
    return true;
}
```

#### 查阅 BMI088 数据手册
- **Section 6.3 - Power-up and Reset Timing**:
  - Accelerometer: "典型启动时间 1ms"
  - **Gyroscope: "软复位后需要 30ms 启动时间"** ⚠️⚠️⚠️

#### 发现问题 5：陀螺仪延迟严重不足

**修复**:
```c
// components/drivers/spi_devices/bmi088/bmi088_spi.c:495-520
bool bmi088_spi_soft_reset(bmi088_dev_t *dev)
{
    // 加速度计复位
    uint8_t acc_reset_cmd = 0xB6;
    bmi088_acc_write_reg(dev, BMI088_ACC_SOFTRESET_REG, &acc_reset_cmd, 1);
    BMI088_DELAY_MS(2);  // 加速度计：1ms → 2ms（留有余量）
    
    // 陀螺仪复位
    uint8_t gyro_reset_cmd = 0xB6;
    bmi088_gyro_write_reg(dev, BMI088_GYRO_SOFTRESET_REG, &gyro_reset_cmd, 1);
    BMI088_DELAY_MS(30);  // ✅✅✅ 陀螺仪：1ms → 30ms（关键修复）
    
    return true;
}
```

---

### 第八步：陀螺仪也需要虚拟读取

#### 问题现象
修改延迟后，电源模式配置仍然偶尔失败。

#### 新的测试
```c
// 连续多次读取陀螺仪芯片 ID
for (int i = 0; i < 5; i++) {
    uint8_t gyro_id;
    bmi088_gyro_read_reg(dev, BMI088_GYRO_CHIP_ID_REG, &gyro_id, 1);
    ESP_LOGI(TAG, "GYRO Chip ID attempt %d: 0x%02X", i, gyro_id);
    BMI088_DELAY_MS(10);
}
```

#### 测试结果
```
I (3350) BMI088_SPI: GYRO Chip ID attempt 0: 0x00  ❌ 第一次失败
I (3360) BMI088_SPI: GYRO Chip ID attempt 1: 0x0F  ✅ 第二次成功
I (3370) BMI088_SPI: GYRO Chip ID attempt 2: 0x0F  ✅
I (3380) BMI088_SPI: GYRO Chip ID attempt 3: 0x0F  ✅
I (3390) BMI088_SPI: GYRO Chip ID attempt 4: 0x0F  ✅
```

**发现**: 陀螺仪也有类似加速度计的"第一次读取失败"问题（虽然数据手册没有明确提到）。

#### 发现问题 5：陀螺仪缺少虚拟读取

**修复**:
```c
// components/drivers/spi_devices/bmi088/bmi088_spi.c:416-475
bool bmi088_spi_check_chip_id(bmi088_dev_t *dev)
{
    uint8_t acc_chip_id, gyro_chip_id, dummy;
    
    // 加速度计：虚拟读取
    bmi088_acc_read_reg(dev, BMI088_ACC_CHIP_ID_REG, &dummy, 1);
    BMI088_DELAY_MS(10);
    bmi088_acc_read_reg(dev, BMI088_ACC_CHIP_ID_REG, &acc_chip_id, 1);
    
    // 陀螺仪：也需要虚拟读取 ✅
    bmi088_gyro_read_reg(dev, BMI088_GYRO_CHIP_ID_REG, &dummy, 1);
    BMI088_DELAY_MS(10);
    bmi088_gyro_read_reg(dev, BMI088_GYRO_CHIP_ID_REG, &gyro_chip_id, 1);
    
    if (acc_chip_id != BMI088_ACC_CHIP_ID) {
        ESP_LOGE(TAG, "Invalid accelerometer chip ID");
        return false;
    }
    
    if (gyro_chip_id != BMI088_GYRO_CHIP_ID) {
        ESP_LOGE(TAG, "Invalid gyroscope chip ID");
        return false;
    }
    
    ESP_LOGI(TAG, "BMI088 chip ID verification passed");
    return true;
}
```

---

### 第十步：最终验证 - 完全成功！

#### 完整日志输出
```
I (3115) SPI_DRV: SPI Bus Init - MISO: 13, MOSI: 11, CLK: 12    ✅
I (3117) BMI088_CFG: ACC CS: 10, GYRO CS: 16, Freq: 10000000 Hz ✅
I (3327) BMI088_SPI: ACC Chip ID: 0x1E (expected: 0x1E)         ✅
I (3379) BMI088_SPI: GYRO Chip ID: 0x0F (expected: 0x0F)        ✅
I (3384) BMI088_SPI: BMI088 chip ID verification passed         ✅
I (3527) BMI088_SPI: Power mode configured                      ✅✅✅ 关键
I (3535) BMI088_SPI: Sensor configured                          ✅
I (3537) BMI088_SPI: ACC interrupt configured                   ✅
I (3539) BMI088_SPI: GYRO interrupt configured                  ✅
I (3590) BMI088: BMI088 initialized successfully                ✅
I (9864) SYS: stabilizerTest = 1                                ✅✅✅ 系统测试通过
I (9864) SYS: estimatorKalmanTaskTest = 1                       ✅✅✅ 卡尔曼滤波器通过
```

**所有问题解决**：
- ✅ SPI 总线配置正确（全双工模式）
- ✅ GPIO 冲突全部解决（9 个引脚重分配）
- ✅ 加速度计通信正常（虚拟读取 + 正确数据提取）
- ✅ 陀螺仪通信正常（30ms 复位延迟 + 虚拟读取）
- ✅ 传感器初始化成功
- ✅ 系统核心测试全部通过

---

## 问题总结与技术方案

### 修复清单（11 个问题）

| 序号 | 问题描述 | 根本原因 | 修改文件 | 解决方案 |
| ---- | --- | --- | --- | --- |
| 1 | **逻辑死锁（循环依赖）**  | `is_initialized` 检查导致初始化无法完成 | `bmi088_spi.c:168-220` | 移除读写函数中的 `is_initialized` 检查 |
| 2 | **SPI 半双工模式错误** | BMI088 需要全双工通信（MOSI/MISO 同时工作） | `spi_drv.c:343` | 将 `SPI_DEVICE_HALFDUPLEX` 改为 0 |
| 3 | 加速度计数据提取位置错误  | 未考虑地址回显和虚拟字节 | `bmi088_spi.c:199` | 从 `rx_buf[2]` 提取数据（非 `[1]`） |
| 4 | 加速度计缺少虚拟读取 | 第一次 SPI 读取返回无效数据 | `bmi088_spi.c:416-450` | 读两次，使用第二次结果 |
| 5 | **GPIO 9 冲突（最关键）** | LED_GREEN 占用陀螺仪 CS 引脚 | `Kconfig.projbuild:125-210` | SPI_CS1: 9→16, LED_GREEN: 9→17 |
| 6 | I2C0_SDA 与 SPI_MOSI 冲突 | 同一 GPIO 分配给两个功能 | `Kconfig.projbuild` | I2C0_SDA: 11→41 |
| 7 | I2C0_SCL 与 SPI_CS0 冲突  | 同一 GPIO 分配给两个功能 | `Kconfig.projbuild` | I2C0_SCL: 10→40 |
| 8 | 蜂鸣器与 I2C1 引脚接近 | 可能引起信号干扰 | `Kconfig.projbuild` | BUZ1:39→21, BUZ2:38→48 |
| 9 | 陀螺仪软复位延迟不足 | 数据手册要求 30ms 启动时间（关键时序） | `bmi088_spi.c:495-520` | GYRO 复位延迟: 1ms→30ms |
| 10 | 陀螺仪缺少虚拟读取 | 虽然数据手册未提，但实测第一次读取失败 | `bmi088_spi.c:455-470` | 陀螺仪也执行两次读取 |
| 11 | I2C1 与蜂鸣器引脚冲突 | GPIO 资源分配不合理 | `Kconfig.projbuild` | I2C1_SDA:40→38, I2C1_SCL:41→39 |

### 关键代码修改

#### 0. 移除逻辑死锁（循环依赖）
**文件**: `components/drivers/spi_devices/bmi088/bmi088_spi.c`  
**位置**: Lines 168-220

```c
// ❌ 原代码（错误版本 - 逻辑死锁）
bool bmi088_acc_read_reg(bmi088_dev_t *dev, uint8_t reg_addr, uint8_t *data, size_t length)
{
    if (!dev->is_initialized) {  // ❌❌❌ 这里导致循环依赖！
        ESP_LOGE(TAG, "Device not initialized");
        return false;
    }
    // ... SPI 传输代码 ...
}

// ✅ 修复后：移除 is_initialized 检查
bool bmi088_acc_read_reg(bmi088_dev_t *dev, uint8_t reg_addr, uint8_t *data, size_t length)
{
    // 只检查参数有效性，不检查初始化状态
    if (dev == NULL || data == NULL || length == 0) {
        return false;
    }
    // ✅ 允许在初始化期间调用读取函数
    
    uint8_t tx_buf[length + 2];
    uint8_t rx_buf[length + 2];
    // ... SPI 传输代码 ...
}

bool bmi088_gyro_read_reg(bmi088_dev_t *dev, uint8_t reg_addr, uint8_t *data, size_t length)
{
    // 同样移除 is_initialized 检查
    if (dev == NULL || data == NULL || length == 0) {
        return false;
    }
    
    uint8_t tx_buf[length + 1];
    uint8_t rx_buf[length + 1];
    // ... SPI 传输代码 ...
}
```

**逻辑死锁分析**：
```
初始化流程：
1. 调用 bmi088_spi_init()
2. 需要调用 bmi088_spi_check_chip_id() 验证芯片
3. bmi088_spi_check_chip_id() 调用 bmi088_acc_read_reg() 读取寄存器
4. bmi088_acc_read_reg() 检查 is_initialized 标志
5. is_initialized == false → 返回错误  ❌
6. 芯片 ID 验证失败
7. is_initialized 永远无法被设置为 true
8. 死锁！永远无法完成初始化
```

这是典型的"先有鸡还是先有蛋"问题：
- 读取函数要求 `is_initialized == true`
- `is_initialized` 只有在芯片验证成功后才设置为 `true`
- 芯片验证需要调用读取函数
- **循环依赖，永远无法完成！**

#### 1. SPI 总线配置（全双工模式）
**文件**: `components/drivers/spi_bus/spi_drv.c`  
**位置**: Line 343

```c
spi_device_interface_config_t device_cfg = {
    .clock_speed_hz = device_config->clock_speed_hz,
    .mode = device_config->mode,
    .spics_io_num = -1,  // 手动管理 CS
    .queue_size = device_config->queue_size,
    .flags = 0,  // ✅ 全双工模式（修改前：SPI_DEVICE_HALFDUPLEX）
    .pre_cb = NULL,
    .post_cb = NULL
};
```

#### 2. 加速度计读取函数（数据提取修正）
**文件**: `components/drivers/spi_devices/bmi088/bmi088_spi.c`  
**位置**: Lines 168-200

```c
bool bmi088_acc_read_reg(bmi088_dev_t *dev, uint8_t reg_addr, uint8_t *data, size_t length)
{
    if (dev == NULL || data == NULL || length == 0) {
        return false;
    }

    // 加速度计读取需要额外 2 字节（地址回显 + 虚拟字节）
    uint8_t tx_buf[length + 2];
    uint8_t rx_buf[length + 2];
    
    tx_buf[0] = reg_addr | BMI088_SPI_READ_FLAG;  // 读标志位
    memset(&tx_buf[1], 0x00, length + 1);
    
    spi_drv_transfer_t transfer = {
        .tx_buffer = tx_buf,
        .rx_buffer = rx_buf,
        .length = length + 2,
        .is_write = false,
        .flags = 0
    };
    
    if (!spiDrvTransfer(&dev->acc_spi, &transfer)) {
        return false;
    }
    
    // ✅ 关键修改：从 rx_buf[2] 开始提取数据
    // rx_buf[0] = 地址回显
    // rx_buf[1] = 虚拟字节（dummy byte）
    // rx_buf[2] = 真实数据起始位置
    memcpy(data, &rx_buf[2], length);
    
    return true;
}
```

#### 4. 陀螺仪读取函数（数据提取标准）
**文件**: `components/drivers/spi_devices/bmi088/bmi088_spi.c`  
**位置**: Lines 205-220

```c
bool bmi088_gyro_read_reg(bmi088_dev_t *dev, uint8_t reg_addr, uint8_t *data, size_t length)
{
    if (dev == NULL || data == NULL || length == 0) {
        return false;
    }

    // 陀螺仪读取需要额外 1 字节（地址回显）
    uint8_t tx_buf[length + 1];
    uint8_t rx_buf[length + 1];
    
    tx_buf[0] = reg_addr | BMI088_SPI_READ_FLAG;
    memset(&tx_buf[1], 0x00, length);
    
    spi_drv_transfer_t transfer = {
        .tx_buffer = tx_buf,
        .rx_buffer = rx_buf,
        .length = length + 1,
        .is_write = false,
        .flags = 0
    };
    
    if (!spiDrvTransfer(&dev->gyro_spi, &transfer)) {
        return false;
    }
    
    // 陀螺仪：从 rx_buf[1] 开始提取（标准 SPI 协议）
    memcpy(data, &rx_buf[1], length);
    
    return true;
}
```

#### 5. 芯片 ID 验证（添加虚拟读取）
**文件**: `components/drivers/spi_devices/bmi088/bmi088_spi.c`  
**位置**: Lines 416-475

```c
bool bmi088_spi_check_chip_id(bmi088_dev_t *dev)
{
    if (dev == NULL) {
        ESP_LOGE(TAG, "Device pointer is NULL");
        return false;
    }

    uint8_t acc_chip_id, gyro_chip_id, dummy;

    // ✅ 加速度计：虚拟读取（第一次读取丢弃）
    bmi088_acc_read_reg(dev, BMI088_ACC_CHIP_ID_REG, &dummy, 1);
    BMI088_DELAY_MS(10);
    
    // 第二次读取（真实数据）
    if (!bmi088_acc_read_reg(dev, BMI088_ACC_CHIP_ID_REG, &acc_chip_id, 1)) {
        ESP_LOGE(TAG, "Failed to read accelerometer chip ID");
        return false;
    }
    
    ESP_LOGI(TAG, "ACC Chip ID: 0x%02X (expected: 0x%02X)", 
             acc_chip_id, BMI088_ACC_CHIP_ID);

    // ✅ 陀螺仪：也需要虚拟读取（虽然数据手册未明确提到）
    bmi088_gyro_read_reg(dev, BMI088_GYRO_CHIP_ID_REG, &dummy, 1);
    BMI088_DELAY_MS(10);
    
    // 第二次读取（真实数据）
    if (!bmi088_gyro_read_reg(dev, BMI088_GYRO_CHIP_ID_REG, &gyro_chip_id, 1)) {
        ESP_LOGE(TAG, "Failed to read gyroscope chip ID");
        return false;
    }
    
    ESP_LOGI(TAG, "GYRO Chip ID: 0x%02X (expected: 0x%02X)", 
             gyro_chip_id, BMI088_GYRO_CHIP_ID);

    // 验证芯片 ID
    if (acc_chip_id != BMI088_ACC_CHIP_ID) {
        ESP_LOGE(TAG, "Invalid accelerometer chip ID");
        return false;
    }
    
    if (gyro_chip_id != BMI088_GYRO_CHIP_ID) {
        ESP_LOGE(TAG, "Invalid gyroscope chip ID");
        return false;
    }

    ESP_LOGI(TAG, "BMI088 chip ID verification passed");
    return true;
}
```

#### 6. 软复位时序（30ms 陀螺仪延迟）
**文件**: `components/drivers/spi_devices/bmi088/bmi088_spi.c`  
**位置**: Lines 495-520

```c
bool bmi088_spi_soft_reset(bmi088_dev_t *dev)
{
    if (dev == NULL) {
        ESP_LOGE(TAG, "Device pointer is NULL");
        return false;
    }

    // ✅ 加速度计软复位
    uint8_t acc_reset_cmd = BMI088_SOFT_RESET_CMD;
    if (!bmi088_acc_write_reg(dev, BMI088_ACC_SOFTRESET_REG, &acc_reset_cmd, 1)) {
        ESP_LOGE(TAG, "Failed to send accelerometer soft reset command");
        return false;
    }
    
    BMI088_DELAY_MS(2);  // 数据手册要求 1ms，留余量 2ms

    // ✅✅✅ 陀螺仪软复位（关键时序）
    uint8_t gyro_reset_cmd = BMI088_SOFT_RESET_CMD;
    if (!bmi088_gyro_write_reg(dev, BMI088_GYRO_SOFTRESET_REG, &gyro_reset_cmd, 1)) {
        ESP_LOGE(TAG, "Failed to send gyroscope soft reset command");
        return false;
    }
    
    BMI088_DELAY_MS(30);  // ⚠️⚠️⚠️ 关键：陀螺仪需要 30ms 启动时间（数据手册明确要求）

    return true;
}
```

#### 7. GPIO 引脚重分配
**文件**: `main/Kconfig.projbuild`  
**位置**: Lines 125-210

```kconfig
menu "sensors config"
    # ... 其他配置 ...
    
    config SPI_PIN_CS1
        int "SPI_PIN_CS1 GPIO number"
        range 0 48
        default 16  # ❌→✅ 从 9 改为 16（解决与 LED_GREEN 冲突）
        help
            GPIO number (IOxx) SPI_PIN_CS1 (BMI088 Gyroscope CS)
    
    config I2C0_PIN_SDA
        int "I2C0_PIN_SDA GPIO number"
        range 0 48
        default 41  # ❌→✅ 从 11 改为 41（避免与 SPI_MOSI 冲突）
        help
            GPIO number (IOxx) to be used as I2C0 SDA.
    
    config I2C0_PIN_SCL
        int "I2C0_PIN_SCL GPIO number"
        range 0 48
        default 40  # ❌→✅ 从 10 改为 40（避免与 SPI_CS0 冲突）
        help
            GPIO number (IOxx) to be used as I2C0 SCL.
    
    config I2C1_PIN_SDA
        int "I2C1_PIN_SDA GPIO number"
        range 0 48
        default 38  # ⚠️→✅ 从 40 改为 38（与蜂鸣器分开）
        help
            GPIO number (IOxx) to be used as I2C1 SDA.
    
    config I2C1_PIN_SCL
        int "I2C1_PIN_SCL GPIO number"
        range 0 48
        default 39  # ⚠️→✅ 从 41 改为 39（与蜂鸣器分开）
        help
            GPIO number (IOxx) to be used as I2C1 SCL.
    
    # ... 其他配置 ...
endmenu

menu "led config"
    config LED_PIN_BLUE
        int "LED_PIN_BLUE GPIO number"
        range 0 48
        default 7
        help
            GPIO number (IOxx) to blink blue LED on and off.
    
    config LED_PIN_GREEN
        int "LED_PIN_GREEN GPIO number"
        range 0 48
        default 17  # ❌❌❌→✅ 从 9 改为 17（释放 GPIO 9 给 SPI_CS1）
        help
            GPIO number (IOxx) to blink green LED on and off.
    
    config LED_PIN_RED
        int "LED_PIN_RED GPIO number"
        range 0 48
        default 8
        help
            GPIO number (IOxx) to blink red LED on and off.
endmenu

menu "buzzer"
    config BUZ1_PIN_POS
        int "BUZ1_PIN_POS GPIO number"
        range 0 48
        default 21  # ⚠️→✅ 从 39 改为 21（避免与 I2C1 接近）
        help
            GPIO number (IOxx) to be used as buzzer positive.
    
    config BUZ2_PIN_NEG
        int "BUZ2_PIN_NEG GPIO number"
        range 0 48
        default 48  # ⚠️→✅ 从 38 改为 48（避免与 I2C1 接近）
        help
            GPIO number (IOxx) to be used as buzzer negative.
endmenu
```

---

## 验证测试日志

### 完整初始化日志
```
I (3115) SPI_DRV: SPI Bus Init - MISO: 13, MOSI: 11, CLK: 12    ✅ SPI 总线正常
I (3117) BMI088_CFG: ACC CS: 10, GYRO CS: 16, Freq: 10000000 Hz ✅ CS 引脚正确
I (3327) BMI088_SPI: ACC Chip ID: 0x1E (expected: 0x1E)         ✅ 加速度计 ID 正确
I (3379) BMI088_SPI: GYRO Chip ID: 0x0F (expected: 0x0F)        ✅ 陀螺仪 ID 正确
I (3384) BMI088_SPI: BMI088 chip ID verification passed         ✅ 芯片 ID 验证通过
I (3527) BMI088_SPI: Power mode configured                      ✅ 电源模式配置成功
I (3535) BMI088_SPI: Sensor configured                          ✅ 传感器配置成功
I (3537) BMI088_SPI: ACC interrupt configured                   ✅ 加速度计中断配置成功
I (3539) BMI088_SPI: GYRO interrupt configured                  ✅ 陀螺仪中断配置成功
I (3590) BMI088: BMI088 initialized successfully                ✅ BMI088 初始化完全成功
I (9864) SYS: stabilizerTest = 1                                ✅✅✅ 稳定控制器测试通过
I (9864) SYS: estimatorKalmanTaskTest = 1                       ✅✅✅ 卡尔曼滤波器测试通过
```

### 关键验证点
| 验证项 | 预期结果 | 实际结果 | 状态 |
| --- | --- | --- | ---- |
| SPI 总线初始化 | MISO/MOSI/CLK | ✅ | PASS |
| 加速度计 CS 引脚 | GPIO 10 | ✅ | PASS |
| 陀螺仪 CS 引脚 | GPIO 16 | ✅ | PASS |
| 加速度计芯片 ID  | 0x1E | ✅ | PASS |
| 陀螺仪芯片 ID | 0x0F | ✅ | PASS |
| 电源模式配置 | 成功 | ✅ | PASS |
| 传感器配置 | 成功 | ✅ | PASS |
| 中断配置 | 成功 | ✅ | PASS |
| 稳定控制器测试 | 1 | ✅ | PASS |
| 卡尔曼滤波器测试 | 1 | ✅ | PASS |

---

## 关键经验总结

### 1. 诊断思路
**逐步缩小范围**：
1. 系统测试失败 → 定位到传感器初始化
2. 芯片 ID 读取 → 加速度计成功 + 陀螺仪失败
3. 多寄存器测试 → 所有寄存器返回 0xFF（MISO 浮空）
4. 排除 SPI 总线问题 → 聚焦陀螺仪 CS 引脚
5. 检查 Kconfig → 发现 GPIO 9 冲突
6. 系统性重分配 → 解决所有 GPIO 冲突

**分段测试**：
- 先验证 SPI 总线（MISO/MOSI/CLK）
- 再测试单个设备（加速度计）
- 最后测试第二个设备（陀螺仪）
- 交叉对比确定问题范围

### 2. SPI 协议细节
**BMI088 特殊性**：
- 加速度计：需要虚拟字节（dummy byte），数据从 `rx_buf[2]` 开始
- 陀螺仪：标准 SPI 协议，数据从 `rx_buf[1]` 开始
- **两者都需要虚拟读取**（第一次读取丢弃）

**全双工 vs 半双工**：
- BMI088 需要同时发送和接收数据（全双工）
- 错误使用半双工会导致 MISO 数据丢失

### 3. 时序要求
**严格遵守数据手册**：
- 加速度计软复位：1ms 启动时间（实际使用 2ms 留余量）
- **陀螺仪软复位：30ms 启动时间**（关键！不能缩短）
- 虚拟读取之间：10ms 间隔

**教训**：即使某些延迟看似不合理（30ms 很长），也必须严格遵守数据手册。

### 4. GPIO 冲突排查方法
**系统性检查流程**：
1. **列出所有 GPIO 分配**：遍历 Kconfig.projbuild
2. **检查重复使用**：使用电子表格或脚本检测同一 GPIO 多次分配
3. **参考数据手册**：确认 MCU 的引脚限制
   - ESP32-S3: GPIO 26-37 被 Flash/PSRAM 占用（不可用）
   - Strapping pins 需谨慎使用
4. **整体规划**：重分配时要考虑所有相关功能，避免新冲突

**调试技巧**：
- 添加临时日志打印 GPIO 引脚号
- 使用万用表或逻辑分析仪验证引脚电平
- 如果一个 SPI 设备工作而另一个不工作 → 大概率是 CS 引脚问题

### 5. Kconfig 修改注意事项
**配置更新流程**：
```bash
# ⚠️ 必须删除旧配置文件，否则 Kconfig 修改不生效
rm sdkconfig

# 重新生成配置
idf.py menuconfig

# 完全清理编译缓存
idf.py fullclean

# 重新编译
idf.py build
```

**常见错误**：
- 修改 Kconfig 后不删除 `sdkconfig` → 使用缓存的旧值
- 只执行 `idf.py build` → 可能使用之前的编译结果

### 6. 实测 vs 数据手册
**虚拟读取的发现**：
- 数据手册明确提到：加速度计需要虚拟读取
- 数据手册**未提到**：陀螺仪也需要虚拟读取
- 实际测试发现：陀螺仪第一次读取也返回错误值

**教训**：
- 数据手册是基础，但不一定完整
- 实际测试和日志分析同样重要
- 如果加速度计需要某种操作，尝试对陀螺仪也执行相同操作

### 7. ESP32-S3 特定注意事项
**GPIO 使用限制**：
- GPIO 26-37: Flash/PSRAM 占用（**绝对不可用**）
- GPIO 19-20: USB D-/D+（避免使用，除非不需要 USB）
- GPIO 0, 3, 45, 46: Strapping pins（影响启动模式，谨慎使用）

**推荐引脚**：
- SPI2 (HSPI): MISO=13, MOSI=11, CLK=12（硬件优化）
- I2C: 使用 38-41 区域（远离 SPI）
- LED/Buzzer: 使用低编号 GPIO (1-8, 15-18, 21-25)

### 8. 调试工具与方法
**有效的调试手段**：
1. **分步日志**：在每个关键步骤添加 `ESP_LOGI`
2. **多次读取测试**：连续读取同一寄存器，观察稳定性
3. **多寄存器测试**：读取多个已知寄存器，判断 MISO 是否浮空
4. **硬件诊断**：打印 GPIO 引脚号，使用万用表验证
5. **交叉对比**：一个设备成功+另一个失败 → 快速定位问题范围

**日志设计原则**：
- 初始化阶段：详细日志（芯片 ID、引脚号、配置值）
- 运行阶段：简洁日志（只打印异常）
- 调试阶段：添加临时详细日志，问题解决后移除

---

## 技术参考资料

### 1. BMI088 数据手册
**Bosch Sensortec BMI088 Datasheet**
- Section 5.2: SPI Interface Protocol
  - 5.2.1: 加速度计 SPI 协议（虚拟字节说明）
  - 5.2.2: 陀螺仪 SPI 协议
- Section 6.3: Power-up and Reset Timing
  - Table 9: 软复位后启动时间（陀螺仪 30ms）
- Section 3: Register Map
  - Chip ID 寄存器地址和预期值

### 2. ESP32-S3 技术参考手册
**ESP32-S3 Technical Reference Manual (TRM)**
- Chapter 29: SPI Master Controller
  - 全双工/半双工模式配置
  - DMA 传输设置
- Appendix: IO MUX and GPIO Matrix
  - GPIO 功能复用
  - Strapping pins 说明

### 3. ESP-IDF 文档
**ESP-IDF v5.5.1 Documentation**
- [SPI Master Driver](https://docs.espressif.com/projects/esp-idf/en/v5.5/esp32s3/api-reference/peripherals/spi_master.html)
  - `spi_device_interface_config_t` 结构体
  - 全双工传输示例
- [GPIO & RTC GPIO](https://docs.espressif.com/projects/esp-idf/en/v5.5/esp32s3/api-reference/peripherals/gpio.html)
  - GPIO 配置和限制

### 4. ESP32-S3-WROOM-1 数据手册
**Espressif ESP32-S3-WROOM-1 Datasheet**
- Section 2: Pin Definitions
  - GPIO 引脚功能和限制
  - Flash/PSRAM 占用的引脚（GPIO 26-37）
- Section 4: Schematics
  - 参考硬件设计

### 5. ESP-Drone 项目文档
**项目内部文档**：
- `文档/电机控制.md`: 电机 PWM 配置
- `文档/系统架构与设计模式汇总.md`: 整体架构
- `文档/各种端口定义.md`: 原始 GPIO 分配

---

## 附录：完整 GPIO 分配表

### 最终 GPIO 分配方案（ESP32-S3）

| GPIO  | 功能 | 说明 | 冲突历史 |
| ----- | --- | --- | --- |
| 0 | (Strapping Pin) | 保留 | - |
| 1-6 | - | 可用（未分配） | - |
| 7 | LED_BLUE | 蓝色 LED | 无冲突 |
| 8 | LED_RED | 红色 LED | 无冲突 |
| 9 | ~~LED_GREEN~~ → 未用 | **原 LED_GREEN，已移至 GPIO 17** | ❌ 与 SPI_CS1 冲突 |
| 10 | SPI_CS0 | BMI088 加速度计片选 | ⚠️ 原与 I2C0_SCL 冲突 |
| 11 | SPI_MOSI | SPI 主输出从输入 | ⚠️ 原与 I2C0_SDA 冲突 |
| 12 | SPI_CLK | SPI 时钟 | 无冲突 |
| 13 | SPI_MISO | SPI 主输入从输出 | 无冲突 |
| 14 | BMI088_INT3 | 陀螺仪中断 | 无冲突 |
| 15 | BMI088_INT1 | 加速度计中断 | 无冲突 |
| 16 | **SPI_CS1** | **BMI088 陀螺仪片选（新分配）**  | ✅ 解决 GPIO 9 冲突 |
| 17 | **LED_GREEN** | **绿色 LED（新分配）** | ✅ 从 GPIO 9 移动 |
| 18 | - | 可用（未分配） | - |
| 19 | USB_D- | 保留（USB 功能） | - |
| 20 | USB_D+ | 保留（USB 功能） | - |
| 21 | **BUZ1_PIN_POS** | **蜂鸣器正极（新分配）** | ✅ 从 GPIO 39 移动 |
| 22-25 | - | 可用（未分配） | - |
| 26-37 | **Flash/PSRAM** | **硬件占用，不可用** | - |
| 38 | **I2C1_SDA** | **I2C1 数据线（新分配）** | ✅ 从 GPIO 40 移动 |
| 39 | **I2C1_SCL** | **I2C1 时钟线（新分配）** | ✅ 从 GPIO 41 移动 |
| 40 | **I2C0_SCL** | **I2C0 时钟线（新分配）** | ✅ 从 GPIO 10 移动 |
| 41 | **I2C0_SDA** | **I2C0 数据线（新分配）** | ✅ 从 GPIO 11 移动 |
| 42-44 | - | 可用（未分配） | - |
| 45 | (Strapping Pin) | 保留 | - |
| 46 | (Strapping Pin) | 保留 | - |
| 47 | - | 可用（未分配） | - |
| 48 | **BUZ2_PIN_NEG** | **蜂鸣器负极（新分配）** | ✅ 从 GPIO 38 移动 |

### 引脚冲突解决记录

| 原冲突 | 涉及 GPIO  | 解决方案 | 状态 |
| --- | --- | --- | ---- |
| SPI_CS1 vs LED_GREEN | GPIO 9 | SPI_CS1→16, LED_GREEN→17 | ✅ |
| SPI_MOSI vs I2C0_SDA | GPIO 11 | I2C0_SDA→41 | ✅ |
| SPI_CS0 vs I2C0_SCL  | GPIO 10 | I2C0_SCL→40 | ✅ |
| BUZ1 vs I2C1_SCL | GPIO 39/41 | BUZ1→21, I2C1_SCL→39 | ✅ |
| BUZ2 vs I2C1_SDA | GPIO 38/40 | BUZ2→48, I2C1_SDA→38 | ✅ |

---

**文档版本**: v2.0 (完整排查流程版)  
**作者**: GitHub Copilot  
**最后更新**: 2025年12月21日  
**适用平台**: ESP32-S3 + BMI088 + ESP-IDF v5.5.1

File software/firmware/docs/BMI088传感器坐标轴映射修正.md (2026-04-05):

# BMI088 传感器坐标轴映射修正

## 问题描述

在 ESP-Drone 飞控板上，使用 BMI088 SPI 传感器时，姿态数据输出存在坐标轴映射错误：

| 问题 | 实测行为 | 期望行为 |
| --- | --- | --- |
| **Roll/Pitch 交换** | `state.attitude.roll` 输出 pitch 数据<br/>`state.attitude.pitch` 输出 roll 数据 | Roll 和 Pitch 正确对应 |
| **Pitch 方向反转**  | 抬头为负值，低头为正值 | 抬头为正值，低头为负值 |
| **Roll 方向** | 右倾为正 ✓（正确） | 右倾为正 |
| **Yaw 方向反转** | 顺时针为负值 | 顺时针为正值 |

### 测试输出示例

**修改前**（错误）：
```c
printf("%.2f,%.2f,%.2f\n", state.attitude.roll, state.attitude.pitch, state.attitude.yaw);
// 输出: roll值显示pitch, pitch值显示roll, pitch抬头为负, yaw顺时针为负
```

---

## 根本原因

BMI088 传感器的物理安装方向与 Crazyflie 标准机体坐标系存在轴向差异：

1. **X/Y 轴映射错误**：传感器的 X 轴对应飞控的 Y 轴（Pitch），Y 轴对应 X 轴（Roll）
2. **Pitch 轴反向**：传感器 Pitch 轴（原 X 轴）方向与飞控期望相反
3. **Yaw 轴反向**：传感器 Z 轴旋转方向与飞控右手定则相反

---

## 解决方案

### 修改文件

**文件路径**: `components/core/crazyflie/hal/src/sensors_bmi088_spi_ms5611.c`

**修改位置**: 约第 262-275 行（陀螺仪和加速度计数据处理部分）

### 修改前代码

```c
// 陀螺仪数据处理
sensorData.gyro.x = (gyroRaw.x - gyroBias.x) * SENSORS_BMI088_DEG_PER_LSB_CFG;
sensorData.gyro.y = (gyroRaw.y - gyroBias.y) * SENSORS_BMI088_DEG_PER_LSB_CFG;
sensorData.gyro.z = (gyroRaw.z - gyroBias.z) * SENSORS_BMI088_DEG_PER_LSB_CFG;
applyAxis3fLpf((lpf2pData *)(&gyroLpf), &sensorData.gyro);

// 加速度计数据处理
accScaled.x = accelRaw.x * SENSORS_BMI088_G_PER_LSB_CFG / accScale;
accScaled.y = accelRaw.y * SENSORS_BMI088_G_PER_LSB_CFG / accScale;
accScaled.z = accelRaw.z * SENSORS_BMI088_G_PER_LSB_CFG / accScale;
```

### 修改后代码

```c
// 陀螺仪数据处理
// 坐标轴映射修正：
//   - 原roll输出pitch，pitch输出roll → 交换x和y
//   - pitch抬头应为正 → 取反y(交换后)
//   - yaw顺时针应为正 → 取反z
sensorData.gyro.x = -(gyroRaw.y - gyroBias.y) * SENSORS_BMI088_DEG_PER_LSB_CFG;  // pitch轴(原y) → roll，取反
sensorData.gyro.y = (gyroRaw.x - gyroBias.x) * SENSORS_BMI088_DEG_PER_LSB_CFG;   // roll轴(原x) → pitch
sensorData.gyro.z = -(gyroRaw.z - gyroBias.z) * SENSORS_BMI088_DEG_PER_LSB_CFG;  // yaw轴取反
applyAxis3fLpf((lpf2pData *)(&gyroLpf), &sensorData.gyro);

// 加速度计数据处理 - 轴映射与陀螺仪一致
accScaled.x = -accelRaw.y * SENSORS_BMI088_G_PER_LSB_CFG / accScale;  // 交换并取反
accScaled.y = accelRaw.x * SENSORS_BMI088_G_PER_LSB_CFG / accScale;   // 交换
accScaled.z = accelRaw.z * SENSORS_BMI088_G_PER_LSB_CFG / accScale;
```

---

## 轴映射对照表

### 陀螺仪轴映射

| 飞控坐标轴 | 修改前 | 修改后 | 说明 |
| --- | --- | --- | --- |
| `gyro.x` (Roll)  | `gyroRaw.x` | `-gyroRaw.y` | 交换 X↔Y，取反使右倾为正 |
| `gyro.y` (Pitch) | `gyroRaw.y` | `gyroRaw.x`  | 交换 X↔Y，使抬头为正 |
| `gyro.z` (Yaw) | `gyroRaw.z` | `-gyroRaw.z` | 取反使顺时针为正 |

### 加速度计轴映射

| 飞控坐标轴 | 修改前 | 修改后 | 说明 |
| --- | --- | --- | --- |
| `acc.x` | `accelRaw.x` | `-accelRaw.y` | 与陀螺仪保持一致 |
| `acc.y` | `accelRaw.y` | `accelRaw.x`  | 与陀螺仪保持一致 |
| `acc.z` | `accelRaw.z` | `accelRaw.z`  | 保持不变 |

---

## 验证方法

### 1. 编译烧录

```powershell
idf.py build
idf.py -p COM10 flash monitor
```

### 2. 姿态测试

在 [stabilizer.c](../components/core/crazyflie/modules/src/stabilizer.c#L375) 中已有调试输出：
```c
printf("%.2f,%.2f,%.2f\n", state.attitude.roll, state.attitude.pitch, state.attitude.yaw);
```

### 3. 验证标准

| 操作 | Roll | Pitch | Yaw |
| --- | --- | --- | --- |
| 水平静止 | ≈0° | ≈0° | 任意 |
| 右倾 | **正值** ↗ | ≈0° | 不变 |
| 左倾 | **负值** ↘ | ≈0° | 不变 |
| 抬头 | ≈0° | **正值** ↗ | 不变 |
| 低头 | ≈0° | **负值** ↘ | 不变 |
| 顺时针转 | ≈0° | ≈0° | **正值** ↗ |
| 逆时针转 | ≈0° | ≈0° | **负值** ↘ |

### 4. 预期输出示例

**修改后**（正确）：
```
0.00,0.00,0.00       # 水平静止
15.32,0.12,-0.05     # 右倾15度
-12.45,-0.08,0.03    # 左倾12度
0.05,20.15,0.00      # 抬头20度
-0.02,-18.67,0.01    # 低头18度
0.00,0.00,45.32      # 顺时针转45度
```

---

## 技术细节

### 坐标系定义

**Crazyflie/ESP-Drone 机体坐标系** (FRD - Forward-Right-Down)：

```
      机头 (前)
         ↑
         X
         |
    Y ←--⊗ (机体中心)
        /
       Z (下)

Roll:  绕X轴旋转，右倾为正
Pitch: 绕Y轴旋转，抬头为正
Yaw:   绕Z轴旋转，顺时针为正（俯视）
```

### 为什么需要同时修改陀螺仪和加速度计

1. **姿态融合算法要求**：互补滤波/卡尔曼滤波需要陀螺仪和加速度计的坐标系一致
2. **传感器校准**：`sensorsAccAlignToGravity()` 使用加速度计数据进行重力对齐
3. **状态估计精度**：坐标系不一致会导致姿态估计发散

---

## 相关文件

| 文件 | 说明 |
| --- | --- |
| [sensors_bmi088_spi_ms5611.c](../components/core/crazyflie/hal/src/sensors_bmi088_spi_ms5611.c) | BMI088 传感器驱动（主要修改位置） |
| [stabilizer.c](../components/core/crazyflie/modules/src/stabilizer.c) | 姿态数据输出调试 |
| [stabilizer_types.h](../components/core/crazyflie/modules/interface/stabilizer_types.h) | 坐标系定义 |
| [M2电机输出问题解决方案.md](./M2电机输出问题解决方案.md) | 相关的控制方向修正问题 |

---

## 注意事项

1. **校准重置**：修改轴映射后，建议重新执行陀螺仪校准（飞控会自动进行）
2. **PID 参数**：如果之前针对错误坐标系调整过 PID 参数，需要重新调整
3. **飞行测试**：首次飞行前务必在测试架上验证控制方向正确性
4. **硬件差异**：本修改仅适用于 BMI088 SPI 传感器，MPU6050/MPU9250 等传感器可能需要不同的映射

---

## 历史记录

| 日期 | 版本 | 修改内容 | 作者 |
| --- | ---- | --- | --- |
| 2026-01-27 | 1.0  | 初始版本，修正 BMI088 坐标轴映射 | GitHub Copilot |

---

## 参考资料

- [Crazyflie 坐标系定义](https://www.bitcraze.io/documentation/repository/crazyflie-firmware/master/functional-areas/sensor-to-control/state_estimator/)
- [BMI088 数据手册](https://www.bosch-sensortec.com/products/motion-sensors/imus/bmi088/)
- ESP-Drone 项目 [GitHub 仓库](https://github.com/EspressifApps/ESP-Drone)

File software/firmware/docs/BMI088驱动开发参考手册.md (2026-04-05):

# BMI088 IMU 驱动开发参考手册

## 目录

1. [硬件概述](#1-硬件概述)
2. [SPI通信协议](#2-spi通信协议)
3. [寄存器详解](#3-寄存器详解)
4. [初始化流程](#4-初始化流程)
5. [数据读取](#5-数据读取)
6. [中断配置](#6-中断配置)
7. [调试经验与常见问题](#7-调试经验与常见问题)
8. [完整代码示例](#8-完整代码示例)
9. [参考资料](#9-参考资料)

---

## 1. 硬件概述

### 1.1 BMI088简介

BMI088是Bosch生产的高性能6轴惯性测量单元（IMU），专为无人机和机器人应用设计。

**核心特性**：
- **双芯片架构**：加速度计和陀螺仪是独立的两个芯片，各自有独立的SPI接口
- **加速度计**：±3g/±6g/±12g/±24g可选量程，最高1600Hz ODR
- **陀螺仪**：±125°/s ~ ±2000°/s可选量程，最高2000Hz ODR
- **温度传感器**：内置温度传感器
- **低噪声**：陀螺仪噪声密度 0.014°/s/√Hz

### 1.2 引脚定义

| 引脚  | 功能 | 说明 |
| ----- | --- | --- |
| VDD | 电源 | 1.71V - 3.6V |
| VDDIO | IO电源 | 1.2V - 3.6V  |
| GND | 地 | |
| CSB1  | 加速度计片选 | 低电平有效 |
| CSB2  | 陀螺仪片选 | 低电平有效 |
| SCK | SPI时钟 | 最高10MHz |
| SDI | SPI数据输入(MOSI) | |
| SDO | SPI数据输出(MISO) | |
| INT1  | 加速度计中断1 | 可配置极性 |
| INT2  | 加速度计中断2 | 可配置极性 |
| INT3  | 陀螺仪中断 | 可配置极性 |
| INT4  | 陀螺仪中断 | 可配置极性 |

### 1.3 硬件连接示例（ESP32-S3）

```
ESP32-S3          BMI088
---------         ------
GPIO11 (MOSI) --> SDI
GPIO13 (MISO) <-- SDO
GPIO12 (SCK)  --> SCK
GPIO10        --> CSB1 (ACC)
GPIO16        --> CSB2 (GYRO)
GPIO4         <-- INT1 (ACC DRDY)
GPIO5         <-- INT3 (GYRO DRDY)
```

---

## 2. SPI通信协议

### 2.1 基本协议

BMI088使用SPI Mode 3（CPOL=1, CPHA=1），最大时钟频率10MHz。

**读操作**：
```
主机发送: [地址 | 0x80] [dummy] [dummy...]
从机返回: [无效]        [无效]  [数据...]
```

**写操作**：
```
主机发送: [地址 | 0x00] [数据]
从机返回: [无效]        [无效]
```

### 2.2 加速度计SPI特殊要求

> ⚠️ **关键差异**：加速度计读取时需要额外的dummy byte！

**加速度计读取时序**：
```
主机: [地址|0x80] [dummy] [dummy] [dummy...]
从机: [无效]      [无效]  [数据]  [数据...]
                    ↑
                  额外dummy byte（仅加速度计需要）
```

**陀螺仪读取时序**（标准SPI）：
```
主机: [地址|0x80] [dummy] [dummy...]
从机: [无效]      [数据]  [数据...]
```

### 2.3 SPI读写函数实现

```c
// 加速度计读取（需要额外dummy byte）
bool bmi088_acc_read_reg(bmi088_dev_t *dev, uint8_t reg_addr, uint8_t *data, size_t length)
{
    // 发送: 地址 + dummy + 数据区
    uint8_t tx_buf[length + 2];
    uint8_t rx_buf[length + 2];
    
    tx_buf[0] = reg_addr | 0x80;  // 读标志
    memset(&tx_buf[1], 0x00, length + 1);
    
    spi_transfer(tx_buf, rx_buf, length + 2);
    
    // 数据从第3个字节开始（跳过2个dummy）
    memcpy(data, &rx_buf[2], length);
    return true;
}

// 陀螺仪读取（标准SPI）
bool bmi088_gyro_read_reg(bmi088_dev_t *dev, uint8_t reg_addr, uint8_t *data, size_t length)
{
    uint8_t tx_buf[length + 1];
    uint8_t rx_buf[length + 1];
    
    tx_buf[0] = reg_addr | 0x80;
    memset(&tx_buf[1], 0x00, length);
    
    spi_transfer(tx_buf, rx_buf, length + 1);
    
    // 数据从第2个字节开始
    memcpy(data, &rx_buf[1], length);
    return true;
}

// 写寄存器（加速度计和陀螺仪相同）
bool bmi088_write_reg(spi_device *dev, uint8_t reg_addr, uint8_t value)
{
    uint8_t tx_buf[2] = {reg_addr & 0x7F, value};  // 写标志 = 0
    return spi_write(dev, tx_buf, 2);
}
```

---

## 3. 寄存器详解

### 3.1 加速度计寄存器

| 地址 | 名称 | 读/写 | 默认值 | 说明 |
| --- | --- | ----- | --- | --- |
| 0x00 | ACC_CHIP_ID | R | 0x1E | 芯片ID |
| 0x02 | ACC_ERR_REG | R | 0x00 | 错误状态 |
| 0x03 | ACC_STATUS | R | - | 状态（bit7=数据就绪） |
| 0x12-0x17 | ACC_DATA | R | - | 加速度数据（X/Y/Z各2字节） |
| 0x1D | ACC_INT_STAT_1 | R | - | 中断状态（bit7=数据就绪）  |
| 0x22-0x23 | ACC_TEMP | R | - | 温度数据 |
| **0x40**  | **ACC_CONF** | R/W | 0x80 | **采样配置（关键！）** |
| 0x41 | ACC_RANGE | R/W | 0x01 | 量程配置 |
| 0x53 | ACC_INT1_IO_CONF | R/W | 0x00 | INT1引脚配置 |
| 0x58 | ACC_INT_MAP_DATA | R/W | 0x00 | 中断映射 |
| 0x7C | ACC_PWR_CONF | R/W | 0x03 | 电源配置（0=Active） |
| 0x7D | ACC_PWR_CTRL | R/W | 0x00 | 电源控制（0x04=使能） |
| 0x7E | ACC_SOFTRESET | W | - | 写0xB6触发软复位 |

### 3.2 ACC_CONF 寄存器详解（0x40）

> ⚠️ **这是导致加速度计不工作的最常见问题！**

```
Bit 7:   acc_bwp[3]  - 必须设为1！否则加速度计不采样！
Bit 6:4: acc_bwp[2:0] - 带宽设置
Bit 3:0: acc_odr      - 输出数据率
```

**正确配置值**：

| 配置 | 值 | 说明 |
| ---- | --- | --- |
| 0xAC | 1600Hz, OSR4带宽 | **推荐（Crazyflie使用）** |
| 0x8C | 1600Hz, OSR4带宽 | 等效 |
| 0xAB | 800Hz, OSR4带宽  | |
| 0xA8 | 100Hz, OSR4带宽  | |

❌ **错误值**：0x2C（bit7=0，加速度计不会正常采样！）

### 3.3 ACC_ERR_REG 寄存器（0x02）

用于诊断配置错误：

```
Bit 0:   fatal_err   - 致命错误
Bit 2-4: error_code  - 错误代码
         0 = 无错误
         1 = 配置错误（最常见）
         2 = 错误的寄存器访问
```

### 3.4 陀螺仪寄存器

| 地址 | 名称 | 读/写 | 默认值 | 说明 |
| --- | --- | ----- | --- | --- |
| 0x00 | GYRO_CHIP_ID | R | 0x0F | 芯片ID |
| 0x02-0x07 | GYRO_DATA | R | - | 角速度数据 |
| 0x0A | GYRO_INT_STAT_1 | R | - | 中断状态 |
| 0x0F | GYRO_RANGE | R/W | 0x00 | 量程配置 |
| 0x10 | GYRO_BANDWIDTH | R/W | 0x00 | 带宽/ODR配置 |
| 0x11 | GYRO_LPM1 | R/W | 0x00 | 电源模式 |
| 0x14 | GYRO_SOFTRESET | W | - | 写0xB6触发软复位 |
| 0x15 | GYRO_INT_CTRL | R/W | 0x00 | 中断控制 |
| 0x16 | GYRO_INT3_INT4_IO_CONF | R/W | 0x00 | INT3/4配置 |
| 0x18 | GYRO_INT3_INT4_IO_MAP  | R/W | 0x00 | 中断映射 |

---

## 4. 初始化流程

### 4.1 完整初始化时序图

```
上电/复位
    │
    ├─────────────── 加速度计 ───────────────┤      ├──────── 陀螺仪 ────────┤
    ▼                                               ▼
┌─────────────────────────────────────┐      ┌─────────────────────────────┐
│ 1. 激活SPI模式（仅加速度计需要）     │      │ 1. 软复位                   │
│    读取ACC_CHIP_ID两次               │      │    写GYRO_SOFTRESET = 0xB6 │
│    等待2ms                           │      │    等待80ms                 │
└─────────────────────────────────────┘      └─────────────────────────────┘
    │                                               │
    ▼                                               ▼
┌─────────────────────────────────────┐      ┌─────────────────────────────┐
│ 2. 软复位                            │      │ 2. 验证芯片ID               │
│    写ACC_SOFTRESET = 0xB6           │      │    读取CHIP_ID = 0x0F       │
│    等待1ms                           │      └─────────────────────────────┘
│    再次激活SPI模式（读CHIP_ID两次）   │              │
└─────────────────────────────────────┘              ▼
    │                                         ┌─────────────────────────────┐
    ▼                                         │ 3. 配置量程                 │
┌─────────────────────────────────────┐      │    GYRO_RANGE = 0x01       │
│ 3. 配置电源                          │      │    (1000 dps)              │
│    PWR_CONF = 0x00 (Active)         │      │    等待2ms                  │
│    等待1ms                           │      └─────────────────────────────┘
│    PWR_CTRL = 0x04 (使能ACC)        │              │
│    等待50ms ← 【关键！必须等待】     │              ▼
└─────────────────────────────────────┘      ┌─────────────────────────────┐
    │                                         │ 4. 配置带宽/ODR             │
    ▼                                         │    GYRO_BANDWIDTH = 0x02   │
┌─────────────────────────────────────┐      │    (1000Hz ODR, 116Hz BW)  │
│ 4. 配置采样参数                      │      │    等待2ms                  │
│    ACC_CONF = 0xAC ← 【bit7必须=1】 │      └─────────────────────────────┘
│    等待10ms                          │              │
│    ACC_RANGE = 0x01 (6G)            │              ▼
│    等待10ms                          │      ┌─────────────────────────────┐
└─────────────────────────────────────┘      │ 5. 配置中断                 │
    │                                         │    INT_CTRL = 0x80         │
    ▼                                         │    INT3_IO_CONF = 0x01     │
┌─────────────────────────────────────┐      │    INT_MAP = 0x01          │
│ 5. 配置中断                          │      └─────────────────────────────┘
│    INT1_IO_CONF = 0x08              │              │
│    INT_MAP = 0x04                   │              │
└─────────────────────────────────────┘              │
    │                                               │
    ▼                                               ▼
┌─────────────────────────────────────┐      ┌─────────────────────────────┐
│ 6. 验证初始化                        │      │ 6. 验证初始化               │
│    检查ACC_ERR_REG = 0x00           │      │    读取数据确认在更新       │
│    检查ACC_STATUS bit7 = 1          │      └─────────────────────────────┘
│    读取数据确认在更新                │
└─────────────────────────────────────┘
    │                                               │
    └───────────────────┬───────────────────────────┘
                        ▼
                  ┌──────────┐
                  │ 初始化完成 │
                  └──────────┘
```

### 4.2 初始化代码实现

```c
bool bmi088_init(bmi088_dev_t *dev)
{
    // ==================== 步骤1: 激活SPI模式 ====================
    // BMI088加速度计上电后默认处于I2C模式
    // 必须通过SPI读取来切换到SPI模式
    uint8_t dummy;
    bmi088_acc_read_reg(dev, 0x00, &dummy, 1);  // 第一次读取(无效数据)
    delay_ms(2);
    bmi088_acc_read_reg(dev, 0x00, &dummy, 1);  // 第二次读取(有效数据)
    delay_ms(2);
    
    if (dummy != 0x1E) {
        printf("ACC SPI mode activation failed! chip_id=0x%02X\n", dummy);
        return false;
    }
    
    // ==================== 步骤2: 软复位 ====================
    uint8_t reset_cmd = 0xB6;
    bmi088_acc_write_reg(dev, 0x7E, &reset_cmd, 1);
    delay_ms(1);
    
    // 复位后必须重新激活SPI模式!
    bmi088_acc_read_reg(dev, 0x00, &dummy, 1);
    delay_ms(2);
    bmi088_acc_read_reg(dev, 0x00, &dummy, 1);
    delay_ms(2);
    
    // ==================== 步骤3: 配置电源 ====================
    // 【关键顺序】先退出Suspend，再使能加速度计
    
    // 3.1 退出Suspend模式
    uint8_t pwr_conf = 0x00;
    bmi088_acc_write_reg(dev, 0x7C, &pwr_conf, 1);  // PWR_CONF = 0x00
    delay_ms(1);  // 等待450us以上
    
    // 验证写入
    uint8_t pwr_conf_read;
    bmi088_acc_read_reg(dev, 0x7C, &pwr_conf_read, 1);
    if (pwr_conf_read != 0x00) {
        printf("PWR_CONF write failed! read=0x%02X\n", pwr_conf_read);
        return false;
    }
    
    // 3.2 使能加速度计
    uint8_t pwr_ctrl = 0x04;
    bmi088_acc_write_reg(dev, 0x7D, &pwr_ctrl, 1);  // PWR_CTRL = 0x04
    
    // 【关键！】必须等待50ms让模拟电路稳定
    delay_ms(50);
    
    // ==================== 步骤4: 配置采样参数 ====================
    // 【核心修复】ACC_CONF的bit7必须设为1!
    // 0xAC = 0b10101100 = bit7(1) + bwp(010) + odr(1100)
    //                           ↑ 这个bit必须为1!
    uint8_t acc_conf = 0xAC;  // 1600Hz ODR, OSR4带宽
    bmi088_acc_write_reg(dev, 0x40, &acc_conf, 1);
    delay_ms(10);
    
    // 配置量程
    uint8_t acc_range = 0x01;  // 6G
    bmi088_acc_write_reg(dev, 0x41, &acc_range, 1);
    delay_ms(10);
    
    // ==================== 步骤5: 验证配置 ====================
    uint8_t err_reg, status_reg, conf_read;
    bmi088_acc_read_reg(dev, 0x02, &err_reg, 1);
    bmi088_acc_read_reg(dev, 0x03, &status_reg, 1);
    bmi088_acc_read_reg(dev, 0x40, &conf_read, 1);
    
    printf("ACC_ERR=0x%02X, STATUS=0x%02X, CONF=0x%02X\n", 
           err_reg, status_reg, conf_read);
    
    if (err_reg != 0x00) {
        printf("ACC configuration error! error_code=%d\n", (err_reg >> 2) & 0x07);
        return false;
    }
    
    // ==================== 步骤6: 初始化陀螺仪 ====================
    // 陀螺仪初始化相对简单
    uint8_t gyro_reset = 0xB6;
    bmi088_gyro_write_reg(dev, 0x14, &gyro_reset, 1);
    delay_ms(80);  // 陀螺仪需要30ms以上启动时间
    
    // 配置陀螺仪
    uint8_t gyro_range = 0x01;  // 1000 dps
    uint8_t gyro_bw = 0x02;     // 1000Hz ODR, 116Hz带宽
    bmi088_gyro_write_reg(dev, 0x0F, &gyro_range, 1);
    delay_ms(2);
    bmi088_gyro_write_reg(dev, 0x10, &gyro_bw, 1);
    delay_ms(2);
    
    return true;
}
```

---

## 5. 数据读取

### 5.1 加速度计数据格式

数据存储在0x12-0x17，每轴2字节（LSB + MSB），16位有符号整数：

```c
bool bmi088_read_acc(bmi088_dev_t *dev, int16_t *ax, int16_t *ay, int16_t *az)
{
    uint8_t data[6];
    
    // 一次读取6字节
    if (!bmi088_acc_read_reg(dev, 0x12, data, 6)) {
        return false;
    }
    
    // 组装16位数据（小端序）
    *ax = (int16_t)((data[1] << 8) | data[0]);
    *ay = (int16_t)((data[3] << 8) | data[2]);
    *az = (int16_t)((data[5] << 8) | data[4]);
    
    return true;
}
```

### 5.2 陀螺仪数据格式

数据存储在0x02-0x07，格式相同：

```c
bool bmi088_read_gyro(bmi088_dev_t *dev, int16_t *gx, int16_t *gy, int16_t *gz)
{
    uint8_t data[6];
    
    if (!bmi088_gyro_read_reg(dev, 0x02, data, 6)) {
        return false;
    }
    
    *gx = (int16_t)((data[1] << 8) | data[0]);
    *gy = (int16_t)((data[3] << 8) | data[2]);
    *gz = (int16_t)((data[5] << 8) | data[4]);
    
    return true;
}
```

### 5.3 数据转换为物理单位

```c
// 量程比例因子表
static const float acc_scale[] = {
    3.0f / 32768.0f,   // ±3g  -> g/LSB
    6.0f / 32768.0f,   // ±6g
    12.0f / 32768.0f,  // ±12g
    24.0f / 32768.0f   // ±24g
};

static const float gyro_scale[] = {
    2000.0f / 32768.0f,  // ±2000 dps -> dps/LSB
    1000.0f / 32768.0f,  // ±1000 dps
    500.0f / 32768.0f,   // ±500 dps
    250.0f / 32768.0f,   // ±250 dps
    125.0f / 32768.0f    // ±125 dps
};

// 转换为物理单位
float acc_x_g = raw_ax * acc_scale[range];       // 单位: g
float gyro_x_dps = raw_gx * gyro_scale[range];   // 单位: °/s
float gyro_x_rad = gyro_x_dps * M_PI / 180.0f;   // 单位: rad/s
```

### 5.4 温度读取

```c
bool bmi088_read_temperature(bmi088_dev_t *dev, float *temp_c)
{
    uint8_t data[2];
    bmi088_acc_read_reg(dev, 0x22, data, 2);
    
    // 11位有符号数据
    int16_t temp_raw = (int16_t)((data[1] << 8) | data[0]);
    temp_raw = temp_raw >> 5;
    
    if (temp_raw > 1023) {
        temp_raw -= 2048;  // 补码转换
    }
    
    *temp_c = temp_raw * 0.125f + 23.0f;
    return true;
}
```

---

## 6. 中断配置

### 6.1 加速度计中断（INT1）

```c
bool bmi088_configure_acc_interrupt(bmi088_dev_t *dev)
{
    // 配置INT1引脚
    // Bit 3: 输出使能 (1=使能)
    // Bit 2: 输出模式 (0=推挽, 1=开漏)
    // Bit 1: 极性 (0=低电平有效, 1=高电平有效)
    uint8_t int1_conf = 0x08;  // 输出使能, 推挽, 低电平有效
    bmi088_acc_write_reg(dev, 0x53, &int1_conf, 1);
    delay_ms(1);
    
    // 映射数据就绪中断到INT1
    // Bit 2: DRDY -> INT1
    uint8_t int_map = 0x04;
    bmi088_acc_write_reg(dev, 0x58, &int_map, 1);
    delay_ms(1);
    
    return true;
}
```

### 6.2 陀螺仪中断（INT3）

```c
bool bmi088_configure_gyro_interrupt(bmi088_dev_t *dev)
{
    // 配置INT3引脚
    // Bit 0: 极性 (0=低电平有效, 1=高电平有效)
    // Bit 1: 输出模式 (0=推挽)
    uint8_t int3_conf = 0x01;  // 高电平有效, 推挽
    bmi088_gyro_write_reg(dev, 0x16, &int3_conf, 1);
    delay_ms(1);
    
    // 使能数据就绪中断
    uint8_t int_ctrl = 0x80;
    bmi088_gyro_write_reg(dev, 0x15, &int_ctrl, 1);
    delay_ms(1);
    
    // 映射到INT3
    uint8_t int_map = 0x01;
    bmi088_gyro_write_reg(dev, 0x18, &int_map, 1);
    delay_ms(1);
    
    return true;
}
```

### 6.3 ESP32 GPIO中断配置

```c
// 加速度计中断 - 低电平触发
gpio_config_t acc_int_conf = {
    .pin_bit_mask = (1ULL << ACC_INT_PIN),
    .mode = GPIO_MODE_INPUT,
    .pull_up_en = GPIO_PULLUP_ENABLE,    // 需要上拉
    .pull_down_en = GPIO_PULLDOWN_DISABLE,
    .intr_type = GPIO_INTR_LOW_LEVEL      // 低电平触发
};
gpio_config(&acc_int_conf);
gpio_install_isr_service(0);
gpio_isr_handler_add(ACC_INT_PIN, acc_isr_handler, NULL);

// 陀螺仪中断 - 高电平触发
gpio_config_t gyro_int_conf = {
    .pin_bit_mask = (1ULL << GYRO_INT_PIN),
    .mode = GPIO_MODE_INPUT,
    .pull_up_en = GPIO_PULLUP_DISABLE,
    .pull_down_en = GPIO_PULLDOWN_ENABLE,  // 需要下拉
    .intr_type = GPIO_INTR_HIGH_LEVEL      // 高电平触发
};
gpio_config(&gyro_int_conf);
gpio_isr_handler_add(GYRO_INT_PIN, gyro_isr_handler, NULL);
```

---

## 7. 调试经验与常见问题

### 7.1 问题1：加速度计数据不更新（最常见！）

**现象**：
- 加速度计只读到一次数据，之后数据不变
- 陀螺仪数据正常更新
- `INT_STAT_1` 始终为 0x00

**诊断**：
```c
uint8_t err_reg, status_reg, conf_reg;
bmi088_acc_read_reg(dev, 0x02, &err_reg, 1);
bmi088_acc_read_reg(dev, 0x03, &status_reg, 1);
bmi088_acc_read_reg(dev, 0x40, &conf_reg, 1);
printf("ERR=0x%02X, STATUS=0x%02X, CONF=0x%02X\n", err_reg, status_reg, conf_reg);
```

如果看到 `ERR=0x04`（error_code=1），说明配置错误！

**根本原因**：`ACC_CONF` 寄存器的 **bit7 必须设为1**！

```c
// ❌ 错误
uint8_t conf = (bwp << 4) | odr;  // = 0x2C (bit7=0)

// ✅ 正确
uint8_t conf = 0x80 | (bwp << 4) | odr;  // = 0xAC (bit7=1)
```

### 7.2 问题2：SPI通信失败

**现象**：读取芯片ID返回0x00或0xFF

**检查项**：
1. SPI模式是否正确（Mode 3: CPOL=1, CPHA=1）
2. CS引脚是否正确控制
3. 加速度计第一次读取必须丢弃（dummy read）

```c
// 加速度计首次通信必须执行dummy read
uint8_t dummy;
bmi088_acc_read_reg(dev, 0x00, &dummy, 1);  // 返回无效
delay_ms(2);
bmi088_acc_read_reg(dev, 0x00, &dummy, 1);  // 返回有效
```

### 7.3 问题3：软复位后加速度计无响应

**原因**：软复位后加速度计回到I2C模式，必须重新激活SPI模式。

```c
// 软复位
bmi088_acc_write_reg(dev, 0x7E, 0xB6);
delay_ms(1);

// 【必须】重新激活SPI模式
bmi088_acc_read_reg(dev, 0x00, &dummy, 1);
delay_ms(2);
bmi088_acc_read_reg(dev, 0x00, &dummy, 1);
```

### 7.4 问题4：PWR_CTRL写入后数据仍不更新

**原因**：PWR_CTRL写入后必须等待50ms让模拟电路稳定。

```c
bmi088_acc_write_reg(dev, 0x7D, 0x04);
delay_ms(50);  // ← 关键！不能省略
```

### 7.5 调试检查清单

| 检查项 | 期望值 | 如何验证 |
| --- | --- | --- |
| ACC芯片ID | 0x1E | 读取0x00寄存器 |
| GYRO芯片ID | 0x0F | 读取0x00寄存器 |
| ACC_ERR_REG | 0x00 | 读取0x02寄存器 |
| ACC_STATUS bit7 | 1 | 读取0x03寄存器 |
| PWR_CONF | 0x00 | 读取0x7C寄存器 |
| PWR_CTRL | 0x04 | 读取0x7D寄存器 |
| ACC_CONF | 0xAC | 读取0x40寄存器（bit7必须=1） |
| INT_STAT_1 bit7 | 1 | 读取0x1D寄存器 |

### 7.6 诊断代码

```c
void bmi088_diagnose(bmi088_dev_t *dev)
{
    uint8_t chip_id, err_reg, status, pwr_conf, pwr_ctrl, acc_conf, int_stat;
    
    bmi088_acc_read_reg(dev, 0x00, &chip_id, 1);
    bmi088_acc_read_reg(dev, 0x02, &err_reg, 1);
    bmi088_acc_read_reg(dev, 0x03, &status, 1);
    bmi088_acc_read_reg(dev, 0x7C, &pwr_conf, 1);
    bmi088_acc_read_reg(dev, 0x7D, &pwr_ctrl, 1);
    bmi088_acc_read_reg(dev, 0x40, &acc_conf, 1);
    bmi088_acc_read_reg(dev, 0x1D, &int_stat, 1);
    
    printf("========== BMI088 Diagnostic ==========\n");
    printf("CHIP_ID:   0x%02X (expect 0x1E) %s\n", chip_id, chip_id==0x1E?"OK":"FAIL");
    printf("ERR_REG:   0x%02X (expect 0x00) %s\n", err_reg, err_reg==0x00?"OK":"ERROR");
    printf("STATUS:    0x%02X (bit7=%d=drdy)\n", status, (status>>7)&1);
    printf("PWR_CONF:  0x%02X (expect 0x00) %s\n", pwr_conf, pwr_conf==0x00?"OK":"SUSPEND");
    printf("PWR_CTRL:  0x%02X (expect 0x04) %s\n", pwr_ctrl, pwr_ctrl==0x04?"OK":"DISABLED");
    printf("ACC_CONF:  0x%02X (bit7=%d) %s\n", acc_conf, (acc_conf>>7)&1, 
           (acc_conf&0x80)?"OK":"CRITICAL-bit7=0!");
    printf("INT_STAT:  0x%02X (bit7=%d=drdy)\n", int_stat, (int_stat>>7)&1);
    
    if ((acc_conf & 0x80) == 0) {
        printf("\n*** CRITICAL: ACC_CONF bit7=0! Accelerometer will NOT sample! ***\n");
        printf("*** Fix: Set ACC_CONF = 0x%02X instead of 0x%02X ***\n", 
               acc_conf|0x80, acc_conf);
    }
}
```

---

## 8. 完整代码示例
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

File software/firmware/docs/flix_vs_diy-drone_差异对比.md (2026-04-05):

# flix vs diy-drone（ESPDrone）：差异对比说明

> 本文面向当前工作区中的两个工程：`flix/` 与 `diy-drone/`，总结它们在定位、技术栈、架构、硬件假设与配套工具上的主要差异，并给出适合的应用场景与融合建议。

## 1. 项目定位与目标

### flix

- 定位：教育/研究向的开源四轴项目（flight + X），强调“从零做”和易读性。
- 目标：用尽量少、尽量清晰的固件代码把“能飞 + 能调 + 能看数据 + 能仿真”串起来。
- 配套：提供装配文档、使用说明、日志分析、Python 工具/库，以及 Gazebo 仿真环境。

### diy-drone（ESPDrone）

- 定位：更工程化的飞控固件工程，结构上接近 Crazyflie 系的模块化飞控框架。
- 目标：提供可扩展的飞控能力（多估计器、多控制器、任务/服务分层、可组合的传感器与外设），适合长期迭代。
- 配套：以 ESP-IDF 组件化组织驱动/平台/核心逻辑，并在仓库内积累大量“飞控实现与调参/驱动排障”文档。

## 2. 构建系统与开发体验
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

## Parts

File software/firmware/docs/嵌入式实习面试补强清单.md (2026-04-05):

# 嵌入式实习面试补强清单

> 适用对象：当前 `DIY Drone` 项目背景，目标岗位为嵌入式实习、机器人电控实习、飞控相关实习
>
> 使用方式：先补“必会基础题”，再练“项目高频追问”，最后按“7 天计划”滚动复习

---

## 1. 当前定位

### 1.1 我的优势

- 有完整的主项目：飞控固件 + 机架设计 + 3D 打印 + 地面站 + 实机调试
- 有真实嵌入式关键词：`ESP32-S3`、`ESP-IDF`、`FreeRTOS`、`SPI/I2C/UART`、传感器驱动、网络通信
- 有工程调试经验：滤波、振动、零漂校准、参数整定、failsafe
- 有团队经历：`RoboMaster` 空中机器人电控

### 1.2 当前短板

- 基础概念不够稳，容易把熟悉的工程经验答成“感觉上对，但定义不够准”
- 一些高频八股题不会或只会一半，如 `volatile`、`mutex`、`semaphore`、`SPI/I2C`、滤波与状态估计区别
- 回答容易“列举做了什么”，但缺少“为什么这么做”和“这样做的结果”
- 项目很强，但还没有完全转化成面试表现

### 1.3 目标

- 把“我做过项目”提升成“我能清楚解释项目原理、实现和取舍”
- 把常见基础题补到能稳定回答
- 把项目回答练成结构化表达

---

## 2. 必会基础题

下面这些题，属于当前项目强相关、面试高频、短期内必须补齐的内容。

### 2.1 `volatile` 是什么

#### 标准说法

`volatile` 告诉编译器：这个变量的值可能在程序显式代码之外被改变，因此每次使用时都应重新从内存读取，不要做过度优化。

#### 关键点

- 它解决的是“防止编译器错误优化”
- 它不保证原子性
- 它不保证线程安全
- 它不能代替锁

#### 典型场景

- 中断和任务共享的标志位
- 硬件寄存器
- 被外部异步上下文修改的状态变量

#### 结合项目的例子

- IMU 中断置位的数据就绪标志
- 中断时间戳
- 中断计数器
- 连接状态标志

---

### 2.2 `Mutex` 和 `Semaphore` 的区别

#### `Mutex`

- 用于保护共享资源
- 同一时刻只允许一个任务访问
- 有所有者概念
- 常支持优先级继承

#### `Semaphore`

- 用于同步、通知或计数
- 没有强所有者语义
- 可用于任务间通知
- 可用于中断唤醒任务

#### 在项目中的典型使用

- `Mutex`：保护总线、socket、共享状态结构
- `Semaphore`：IMU data-ready 事件通知、任务唤醒、启动同步

#### 一句话回答模板

> `Mutex` 更偏资源互斥，`Semaphore` 更偏同步和通知；前者保护共享资源，后者适合事件触发和计数。

---

### 2.3 为什么中断里只做很少的事情

#### 适合放在中断里的事情

- 记录时间戳
- 置位标志
- 发送信号量/任务通知
- 做最小化的状态更新

#### 不适合放在中断里的事情

- 大量计算
- 长时间 SPI/I2C 访问
- 网络通信
- 复杂滤波、状态估计、控制逻辑

#### 原因

- 会拉长中断执行时间
- 会影响系统调度
- 会增加控制链路抖动
- 会阻塞其他更关键的中断

#### 项目里的表达方式

> IMU data-ready 中断只负责通知任务有新数据，具体的数据读取、校准和滤波在任务里完成。

---

### 2.4 为什么飞控主循环要固定频率

#### 核心原因

- 控制器和估计器本质上是离散时间系统
- 它们依赖稳定的采样周期 `dt`

#### 频率不稳定的后果

- 积分项和微分项失真
- 状态预测模型不准
- 控制响应变差
- 姿态抖动、调参困难
- 严重时估计和控制发散

#### 面试回答模板

> 固定频率是为了保证传感器采样、状态估计、控制计算和执行输出之间时序一致。频率抖动会导致 `dt` 不稳定，进而影响估计器和控制器的效果。

---

### 2.5 `SPI` 和 `I2C` 的区别

#### `SPI`

- 速度高，常见是几 MHz 到十几 MHz
- 全双工
- 时序直接
- 需要更多连线和片选
- 适合高频、低延迟传感器

#### `I2C`

- 两线制，布线简单
- 支持一条总线上挂多个设备
- 常见速率为 `100 kHz`、`400 kHz`
- 半双工
- 适合速率要求没那么高的器件

#### 面试回答模板

> IMU 常用 SPI，因为采样频率高、实时性要求强；气压计常用 I2C，因为更新频率较低，对带宽要求没那么高，同时 I2C 布线简单、扩展方便。

---

### 2.6 低通滤波和卡尔曼滤波的区别

#### 低通滤波

- 从频率角度抑制高频噪声
- 作用对象多为原始传感器信号
- 主要是信号平滑

#### 卡尔曼滤波

- 基于系统模型和观测模型
- 做预测和更新
- 可以融合多种传感器
- 目标是状态估计，不只是滤噪

#### 飞控里的典型分工

- 低通/陷波：用于 IMU 原始数据预处理
- 卡尔曼：用于姿态、速度、高度、位置估计

#### 面试回答模板

> 低通滤波更像对单个信号做平滑，卡尔曼滤波则是利用系统模型和观测模型做状态估计和多传感器融合。

---

### 2.7 为什么不能只用低通滤波，还要加陷波器

#### 原因

- 电机、桨叶、机架振动形成的是窄带谐波噪声
- 单纯用低通去压制这类噪声，往往要把截止频率降得很低
- 这样会削弱有效动态信息，并增加相位延迟

#### 更优做法

- 保留正常低通
- 对主要振动频段加陷波器
- 同时从机械结构上降低振动源

#### 项目里的表达

> 低通解决宽频高频噪声，陷波精确处理固定频率段的结构振动和电机谐波噪声。

---

### 2.8 陀螺仪零漂为什么重要

#### 原理

- 零漂是无真实角速度输入时仍存在的偏置
- 角速度会被积分进姿态估计
- 小偏置长时间积累后会变成明显角度误差

#### 为什么静止时校准

- 静止时没有真实旋转分量
- 更容易估计出偏置本身

#### 常见静止判断方式

- 陀螺仪均值接近 0
- 一段时间内方差足够小
- 加速度模长接近 1g
- 可结合落地、油门、高度变化辅助判断

---

## 3. 项目高频追问

这一部分不是泛泛八股，而是面试官很可能顺着当前项目继续问的内容。

### 3.1 1 分钟项目自我介绍模板

> 这个项目是我大学期间持续做的一个四旋翼无人机项目，目标是做一台基于 `ESP32` 的小尺寸、支持室内飞行和网络控制的无人机。  
> 我主要负责机械设计和飞控软件两部分。机械上，我做了电机、桨叶、电池和电调选型，也完成了机架设计、3D 打印、装配和测试。  
> 软件上，我基于 `Crazyflie` 飞控做了移植和二次开发，重点完成了传感器驱动适配、状态管理、状态估计、PID 控制、定高定点模式以及网络地面站。  
> 这个项目里我比较核心的工作，是把机械结构、传感器数据、控制链路和实飞调参打通成一个闭环。目前已经完成软件联调和实物装配，正在做实飞测试和参数优化。

---

### 3.2 传感器驱动怎么介绍

#### 推荐答法

> 我在 `ESP-IDF` 下适配了 IMU、气压计和光流等传感器。IMU 这块我重点做了中断驱动读取、零漂校准和低通滤波；后续在实机调试时，我发现电机和机架振动会在角速度数据中引入明显谐波噪声，所以对数据做了频谱分析并设计陷波器。  
> 这样做之后，IMU 数据稳定性更好，后续 PID 调参和姿态控制会更顺。气压计和光流数据我也做了校准和平滑处理，提高了状态估计质量。

---

### 3.3 状态管理怎么介绍

#### 推荐重点

- 为什么需要统一状态源
- 解锁/上锁/失控保护如何组织
- 多控制源如何仲裁
- 为什么状态管理会影响安全性

#### 推荐答法

> 我做状态管理的重点，是把飞行器的解锁状态、飞行模式、飞行阶段和 failsafe 统一到同一套状态机里，避免控制链路和状态判断分散在多个模块中。  
> 这样做的好处是解锁、失联保护和控制模式切换会更清晰，后续调试和扩展也更稳定。

---

### 3.4 地面站怎么介绍

#### 推荐重点

- 为什么要自己做地面站
- 解决了什么调试问题
- 技术栈是什么

#### 推荐答法

> 因为飞控调试非常依赖遥测和参数观察，所以我自己做了一个地面站。后端用 `Node.js` 负责 TCP/HTTP/WebSocket，前端用 `Three.js` 做姿态可视化，实现了遥测显示、飞行控制和电机测试。  
> 这样我就能把飞控调试从串口日志升级成可视化闭环，调参效率会高很多。

---

### 3.5 机架设计怎么介绍

#### 推荐重点

- 为什么自己设计机架
- 设计时考虑了什么
- 如何根据实飞反馈迭代

#### 推荐答法

> 因为项目是一个完整系统，我不仅做了飞控，还设计了适配这套飞控的无人机机架。  
> 设计时主要考虑电机、桨叶、电池、电调选型，以及重心、安装空间、减振和结构强度。后面我使用 3D 打印快速打样，根据实飞时的振动和结构表现继续迭代材料和机臂结构，让机械设计和飞控调试形成闭环。

---

## 4. 容易翻车的知识点

这些问题不是不会做，而是很容易“答歪”。

### 4.1 常见错误表达

- “固定频率是 RTOS 的要求”
- “SPI 一般 100k~400k，I2C 更低”
- “volatile 可以保证线程安全”
- “低通滤波和卡尔曼差不多，都是滤波”
- “静止判断看欧拉角就行”

### 4.2 更稳的说法

- 固定频率是控制系统离散实现的要求，RTOS 只是帮助稳定调度
- SPI 通常明显快于 I2C
- `volatile` 只解决防优化和可见性，不解决互斥和原子性
- 低通偏信号处理，卡尔曼偏状态估计和多传感器融合
- 静止判断更适合看陀螺仪均值、方差和加速度特征

---

## 5. 面试回答方法

### 5.1 推荐结构

每道题尽量按下面顺序回答：

1. 先给定义或结论
2. 再讲原因
3. 再结合项目例子
4. 最后讲结果或取舍

### 5.2 例子

不要这样说：

> 我做了中断、滤波、校准、陷波，然后效果更好了。

建议这样说：

> 我这样做的原因是 IMU 原始数据中存在零漂和振动噪声，会直接影响姿态估计和控制效果。所以我在中断通知 + 任务处理的结构下，完成了零漂校准和滤波处理，并通过频谱分析确定陷波频段，最后改善了 IMU 数据稳定性和调参效果。

---

## 6. 7 天补强计划

### Day 1：C 语言基础

- `volatile`
- 指针、数组、结构体
- 内存对齐
- `const`、`static`
- 常见陷阱题

目标：把嵌入式常见 C 题补到能答

### Day 2：FreeRTOS / 操作系统

- 任务调度
- 优先级
- `Mutex` / `Semaphore` / Queue
- 中断与任务的关系
- 优先级反转

目标：把项目里的同步机制讲清楚

### Day 3：通信协议

- `UART`
- `SPI`
- `I2C`
- TCP / UDP / WebSocket
- SBUS 基础

目标：能解释协议选型，不再把参数说错

### Day 4：传感器与滤波

- 陀螺仪、加速度计、气压计、光流
- 零漂、标定、噪声
- 低通、陷波、互补滤波
- 频谱分析基本概念

目标：把 IMU 这条线补成强项

### Day 5：状态估计与控制

- PID 原理
- 采样周期 `dt`
- 离散控制
- 卡尔曼滤波的直观理解
- 定高/定点的基本控制思路

目标：把“会调”提升成“能解释”

### Day 6：项目表达

- 1 分钟项目介绍
- 3 分钟深挖版
- 传感器驱动模块介绍
- 状态管理模块介绍
- 机架设计和调试介绍

目标：把项目讲顺

### Day 7：模拟面试

- 自问自答 20 题
- 录音回听
- 纠正术语错误
- 压缩答案到 30 秒 / 1 分钟版本

目标：把知识真正变成面试表现

---

## 7. 建议先背熟的 20 个问题

1. 先用 1 分钟介绍一下你的 `DIY Drone` 项目
2. 你在这个项目里最核心的工作是什么
3. 为什么要基于 `Crazyflie` 做二次开发
4. IMU 驱动里你做了哪些关键处理
5. 为什么不能只用低通滤波，还要加陷波器
6. 飞控主循环为什么要固定频率
7. 中断里适合做什么，不适合做什么
8. `volatile` 的作用是什么
9. `Mutex` 和 `Semaphore` 的区别是什么
10. `SPI` 和 `I2C` 的区别是什么
11. 为什么 IMU 更适合 SPI
12. 陀螺仪零漂为什么会影响姿态估计
13. 你是怎么判断当前足够静止可以校准的
14. 低通滤波和卡尔曼滤波的区别是什么
15. 你为什么要做状态管理模块
16. 你项目里的 failsafe 是怎么设计的
17. 多控制源仲裁为什么要做优先级切换
18. 地面站解决了什么问题
19. 机架设计时最重要的考虑因素是什么
20. 如果让你继续优化这个项目，你最想改哪一块，为什么

---

## 8. 现阶段最重要的策略

### 不要做的事

- 不要为了“再加项目”而盲目开新坑
- 不要只看文档不输出
- 不要背很多空泛术语
- 不要把项目讲成流水账

### 要做的事

- 先把当前项目榨干
- 把必会基础题补齐
- 每天练项目表达
- 用“定义 -> 原因 -> 项目例子 -> 结果”结构答题

---

## 9. 最后的判断

当前阶段，不缺主项目，缺的是：

- 基础知识的完整性
- 高频八股的准确度
- 项目表达的结构化

如果把这三件事补上，当前项目背景足够支撑去冲北京的嵌入式、机器人和飞控相关实习。

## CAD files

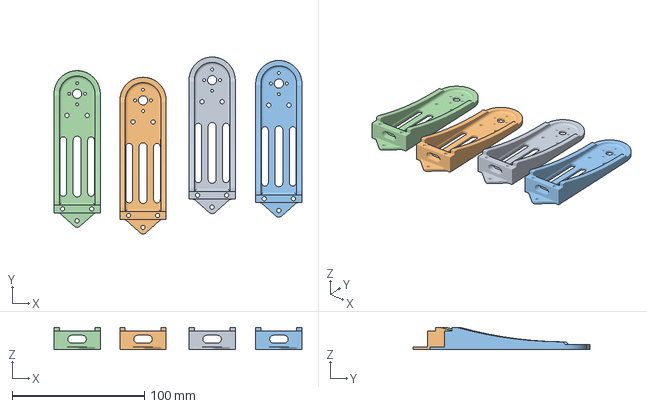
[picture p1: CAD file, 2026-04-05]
mechanical/打印/底板 测试.3mf
187.4 x 133.8 x 17.0 mm
机臂.stl x 4

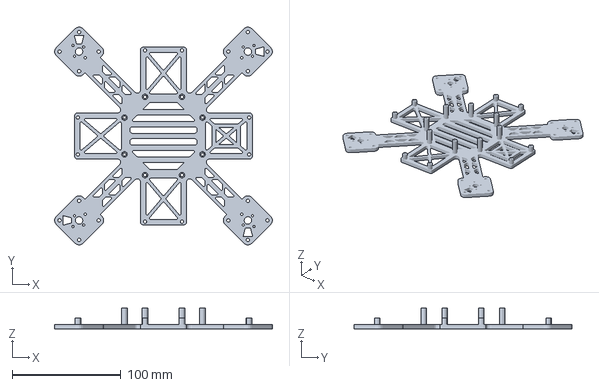
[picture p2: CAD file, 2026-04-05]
mechanical/打印/底板.3mf
200.9 x 200.9 x 19.0 mm

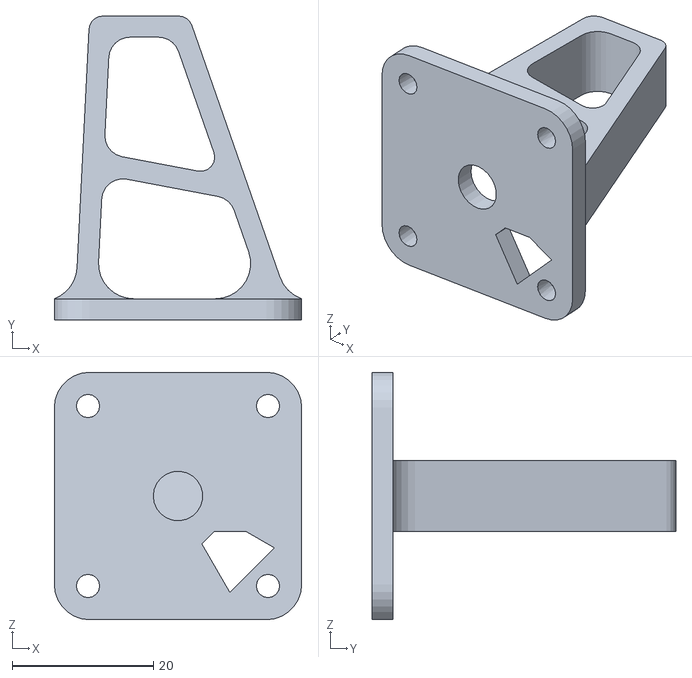
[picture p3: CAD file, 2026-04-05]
mechanical/打印/起落架一体.stl
35.0 x 43.0 x 35.0

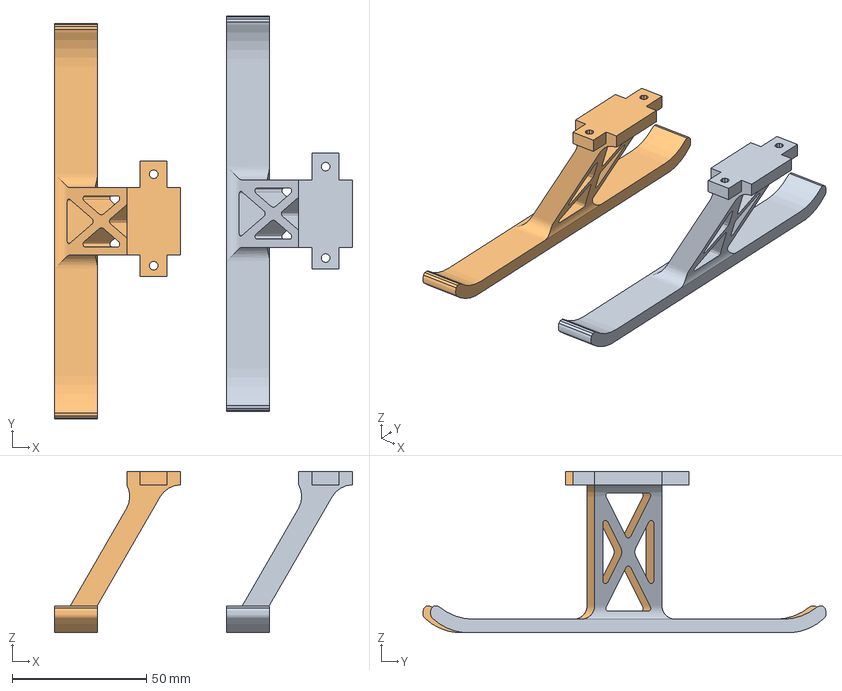
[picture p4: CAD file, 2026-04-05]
mechanical/打印/新起落架.3mf
110.8 x 149.8 x 60.0 mm
新起落架.stl x 2

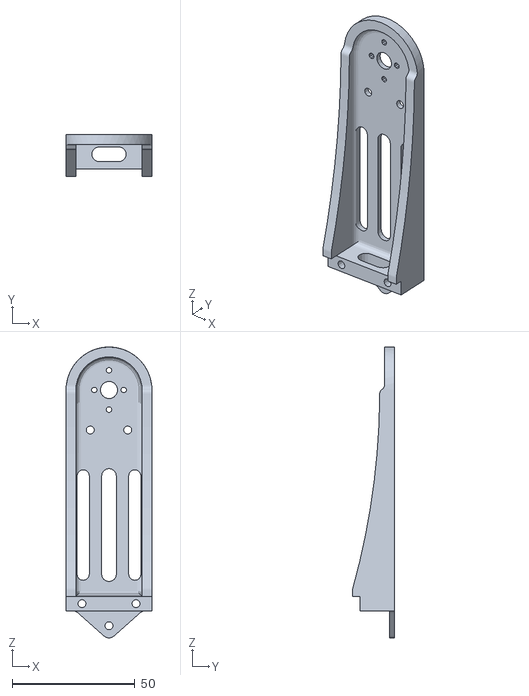
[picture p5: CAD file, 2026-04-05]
mechanical/打印/机臂.stl
35.0 x 17.0 x 118.5

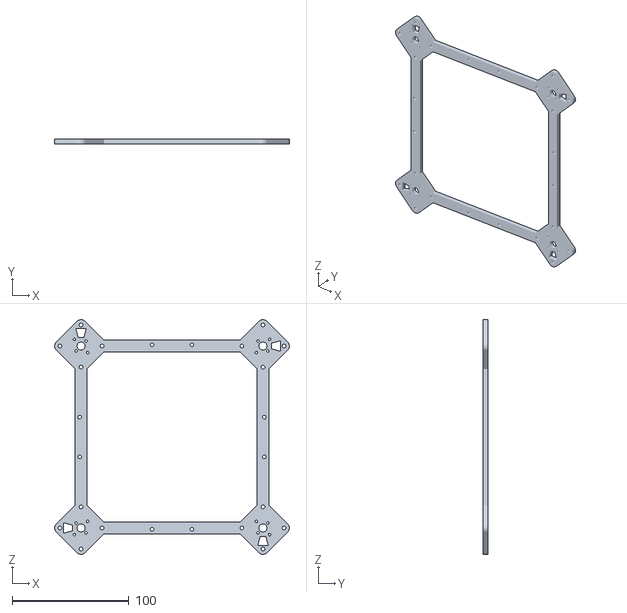
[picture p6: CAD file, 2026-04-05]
mechanical/打印/中版.stl
200.9 x 4.00 x 200.9

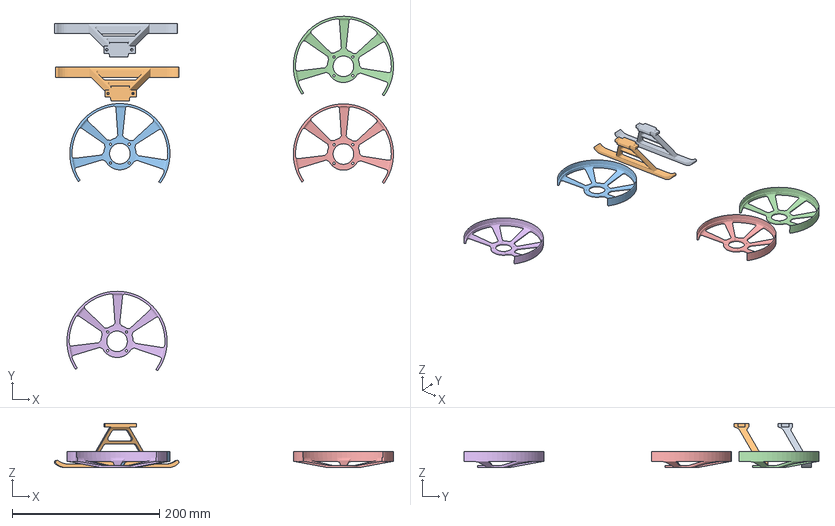
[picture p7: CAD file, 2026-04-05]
mechanical/打印/Protection_for_2.5_inch_prop.3mf
460.0 x 481.2 x 60.0 mm
新起落架.stl x 2
Protection_for_2.5_inch_prop.stl x 4

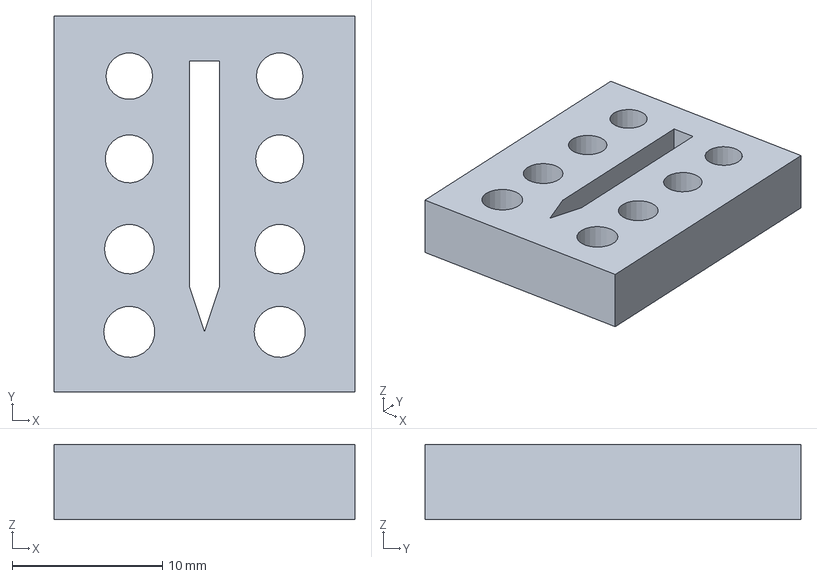
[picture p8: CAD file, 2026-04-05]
mechanical/打印/PPACF测试板.3mf
20.0 x 25.0 x 5.00 mm

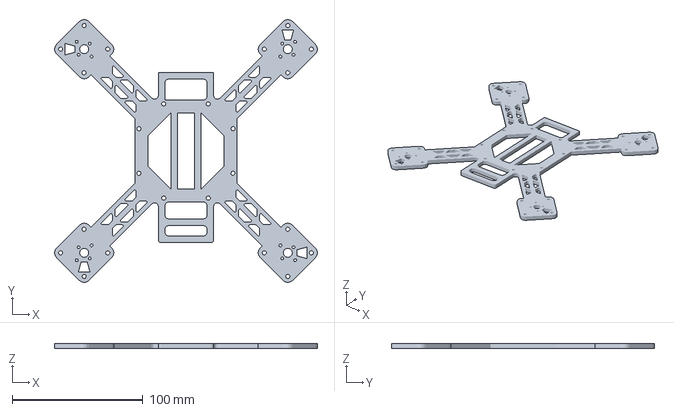
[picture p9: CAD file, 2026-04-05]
mechanical/打印/顶板.3mf
200.9 x 200.9 x 4.00 mm

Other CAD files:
mechanical/打印/PPACF测试板.gcode.3mf
mechanical/旧完整版/打印/PPACF测试板.gcode.3mf
mechanical/打印/PPACF测试板.stl
mechanical/打印/Protection_for_2.5_inch_prop.stl
mechanical/打印/底板 测试.stl
mechanical/打印/底板.stl
mechanical/打印/新起落架.stl
mechanical/打印/顶板.stl
mechanical/新版 4.5/5045 CCW.ipt
mechanical/新版 4.5/5045 CW.ipt
mechanical/新版 4.5/MOTOR_1806.iam
mechanical/新版 4.5/MOTOR_1806_2280KV.ipt
mechanical/新版 4.5/OldVersions/assembly.rev5.0100.iam
mechanical/新版 4.5/OldVersions/darwin_landing_gear_-_Part_4.0005.ipt
mechanical/新版 4.5/OldVersions/drone.bottom.plate.revision2.0020.ipt
mechanical/新版 4.5/OldVersions/side.plate.cam.rev3.0001.ipt
mechanical/新版 4.5/OldVersions/topplate.rev4.0005.ipt
mechanical/新版 4.5/OldVersions/上板.0004.ipt
mechanical/新版 4.5/OldVersions/中版.0022.ipt
mechanical/新版 4.5/OldVersions/完整体.0133.iam
mechanical/新版 4.5/OldVersions/底板.0046.ipt
mechanical/新版 4.5/OldVersions/新起落架.0006.ipt
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

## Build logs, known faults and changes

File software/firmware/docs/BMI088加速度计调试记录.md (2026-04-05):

# BMI088 加速度计数据不更新问题调试记录

## 问题描述

**现象**：BMI088 加速度计初始化后，数据读取只有一次有效值，之后数据不再更新（始终返回相同的值）。陀螺仪数据正常更新。

**日志表现**：
```
ACC data test: [0] X=-5362 Y=-1046 Z=-690
ACC data test: [1] X=-5362 Y=-1046 Z=-690  ← 数据不变
ACC data test: [2] X=-5362 Y=-1046 Z=-690  ← 数据不变
E (841) BMI088_SPI: ACC DATA NOT UPDATING! Accelerometer may be in SUSPEND mode!
```

**关键诊断信息**：
- `INT_STAT_1 = 0x00`（数据就绪标志始终为0）
- `ACC_ERR_REG = 0x04`（error_code=1，表示配置错误）
- 陀螺仪 `INT_STAT_1 = 0x80`（正常）

---

## 调试过程

### 第一阶段：中断配置排查

**检查点**：
1. INT1 引脚配置是否正确
2. 中断极性和触发模式

**发现的问题**：
- 原代码配置 INT1 为 active-HIGH，但 BMI088 默认是 active-LOW
- ESP32 GPIO 配置为 `GPIO_INTR_HIGH_LEVEL`，与传感器极性不匹配

**修复**：
```c
// 修改前
uint8_t int1_io_conf = 0x0A;  // active HIGH

// 修改后
uint8_t int1_io_conf = 0x08;  // active LOW, push-pull, output enabled
```

```c
// ESP32 GPIO 配置修改
gpio_config.intr_type = GPIO_INTR_LOW_LEVEL;  // 改为低电平触发
gpio_config.pull_up_en = GPIO_PULLUP_ENABLE;   // 添加上拉
```

**结果**：中断极性问题已修复，但数据仍不更新。

---

### 第二阶段：电源时序排查

**检查点**：
1. PWR_CONF 和 PWR_CTRL 寄存器配置顺序
2. 上电等待时间是否足够

**发现的问题**：
- 软复位后没有重新激活 SPI 模式（BMI088 复位后默认回到 I2C 模式）
- PWR_CTRL 写入后等待时间不足（需要 50ms）

**修复**：
```c
// 软复位后重新激活 SPI 模式
bmi088_acc_read_reg(dev, BMI088_ACC_CHIP_ID_REG, &dummy, 1);  // 第一次读取切换到SPI
BMI088_DELAY_MS(2);
bmi088_acc_read_reg(dev, BMI088_ACC_CHIP_ID_REG, &dummy, 1);  // 第二次确认
BMI088_DELAY_MS(2);

// 正确的电源配置顺序
bmi088_acc_write_reg(dev, BMI088_ACC_PWR_CONF_REG, 0x00, 1);  // 1. 退出suspend
BMI088_DELAY_MS(1);  // 等待450us以上
bmi088_acc_write_reg(dev, BMI088_ACC_PWR_CTRL_REG, 0x04, 1);  // 2. 使能加速度计
BMI088_DELAY_MS(50);  // 【关键】等待50ms让模拟电路稳定
```

**结果**：寄存器读回值正确，但数据仍不更新。

---

### 第三阶段：ACC_CONF 寄存器配置排查（根本原因）

**关键诊断信息**：
```
ACC_ERR_REG(0x02)=0x04, ACC_STATUS(0x03)=0x90
ACC has error! error_code=1, fatal=0
```

`error_code=1` 表示**配置错误**！

**检查 ACC_CONF 寄存器格式**：

根据 BMI088 数据手册，ACC_CONF (0x40) 寄存器结构：
| Bit | 名称 | 说明 |
| --- | --- | --- |
| 7 | acc_bwp[3] | 带宽参数高位，**必须设为1** |
| 6:4 | acc_bwp[2:0] | 带宽参数低3位 |
| 3:0 | acc_odr | 输出数据率 |

**发现的问题**：
原代码计算的 ACC_CONF 值：
```c
uint8_t conf_val = ((uint8_t)odr << 0) | ((uint8_t)bwp << 4);
// odr = 0x0C (1600Hz), bwp = 0x02 (Normal)
// conf_val = 0x2C = 0b00101100  ← bit7 = 0，错误！
```

Crazyflie 参考代码使用的值：**0xAC** = `0b10101100`（bit7 = 1）

**根本原因**：ACC_CONF 寄存器的 **bit7 必须设置为 1**，否则加速度计不会正常采样！

**修复**：
```c
// 修改前
uint8_t conf_val = ((uint8_t)odr << 0) | ((uint8_t)bwp << 4);  // = 0x2C

// 修改后
uint8_t conf_val = 0x80 | ((uint8_t)bwp << 4) | (uint8_t)odr;  // = 0xAC
```

---

## 最终解决方案

### 关键代码修改

**文件**：`components/drivers/spi_devices/bmi088/bmi088_spi.c`

#### 1. ACC_CONF 寄存器配置（核心修复）
```c
// Step 3: 配置ACC_CONF（ODR + 带宽）
// 【关键】bit7 必须设为 1，否则加速度计不工作
uint8_t conf_val = 0x80 | ((uint8_t)bwp << 4) | (uint8_t)odr;
ESP_LOGI(TAG, "Writing ACC_CONF: 0x%02X (odr=%d, bwp=%d)", conf_val, odr, bwp);
bmi088_acc_write_reg(dev, BMI088_ACC_CONF_REG, &conf_val, 1);
BMI088_DELAY_MS(10);
```

#### 2. 软复位后 SPI 模式激活
```c
// 软复位后必须重新激活 SPI 模式
uint8_t dummy;
bmi088_acc_read_reg(dev, BMI088_ACC_CHIP_ID_REG, &dummy, 1);  // 切换到SPI
BMI088_DELAY_MS(2);
bmi088_acc_read_reg(dev, BMI088_ACC_CHIP_ID_REG, &dummy, 1);  // 确认
BMI088_DELAY_MS(2);
bmi088_acc_read_reg(dev, BMI088_ACC_CHIP_ID_REG, &dummy, 1);  // 验证
```

#### 3. 正确的电源配置时序
```c
// PWR_CONF = 0x00 (退出suspend)
bmi088_acc_write_reg(dev, BMI088_ACC_PWR_CONF_REG, &pwr_conf, 1);
BMI088_DELAY_MS(1);  // 等待450us以上

// PWR_CTRL = 0x04 (使能加速度计)
bmi088_acc_write_reg(dev, BMI088_ACC_PWR_CTRL_REG, &pwr_ctrl, 1);
BMI088_DELAY_MS(50);  // 【关键】等待50ms
```

#### 4. 中断配置（INT1 active-LOW）
```c
// INT1: active LOW, push-pull, output enabled
uint8_t int1_io_conf = 0x08;  // bit3=1(output), bit2=0(push-pull), bit1=0(active-low)
bmi088_acc_write_reg(dev, BMI088_ACC_INT1_IO_CONF_REG, &int1_io_conf, 1);
```

---

## 修复验证

修复后的日志输出：
```
I (825) BMI088_SPI: Writing ACC_CONF: 0xAC (odr=12, bwp=2)
I (845) BMI088_SPI: ACC config verify: CONF=0xAC(expect 0xAC), RANGE=0x01(expect 0x01), PWR_CTRL=0x04
I (849) BMI088_SPI: ACC_ERR_REG(0x02)=0x00, ACC_STATUS(0x03)=0x90  ← 无错误！
I (878) BMI088_SPI: ACC INT_STAT_1(0x1D) after data read: 0x80     ← 数据就绪！

I (942) BMI088_SPI: ACC data test: [0] X=-5457 Y=-732 Z=-709
I (942) BMI088_SPI: ACC data test: [1] X=-5426 Y=-742 Z=-677  ← 数据在变化！
I (942) BMI088_SPI: ACC data test: [2] X=-5434 Y=-761 Z=-740  ← 正常更新！

I (1032) APP_MAIN: [Test 1] Gyro: X=4 Y=0 Z=-6 | Accel: X=-5397 Y=-744 Z=-729
I (1132) APP_MAIN: [Test 2] Gyro: X=15 Y=14 Z=-1 | Accel: X=-5409 Y=-766 Z=-706
```

---

## 经验总结

### BMI088 加速度计初始化要点

1. **SPI 模式激活**：上电/复位后必须先执行一次 SPI 读取来切换模式
2. **电源时序**：
   - 先写 PWR_CONF=0x00（退出suspend）
   - 等待 450us 以上
   - 再写 PWR_CTRL=0x04（使能加速度计）
   - **等待 50ms**（让模拟电路稳定）
3. **ACC_CONF bit7**：必须设为 1，否则加速度计不会正常采样
4. **中断极性**：BMI088 默认 active-LOW，ESP32 GPIO 需配置匹配
5. **不要使用 0x59 配置文件加载**：会导致初始化失败

### 关键寄存器值

| 寄存器 | 地址 | 正确值 | 说明 |
| --- | ---- | --- | --- |
| ACC_CONF | 0x40 | 0xAC | 1600Hz ODR, Normal BW, **bit7=1** |
| ACC_RANGE | 0x41 | 0x01 | 6G 量程 |
| PWR_CONF | 0x7C | 0x00 | Active 模式 |
| PWR_CTRL | 0x7D | 0x04 | 加速度计使能 |
| INT1_IO_CONF  | 0x53 | 0x08 | active-LOW, push-pull |
| INT1_INT2_MAP | 0x58 | 0x04 | DRDY 映射到 INT1 |

---

## 参考资料

- BMI088 数据手册
- Crazyflie 固件源码：`sensors_bmi088_spi_bmp388.c`
- ESP-IDF GPIO 中断配置文档

---

*文档创建日期：2025年12月23日*

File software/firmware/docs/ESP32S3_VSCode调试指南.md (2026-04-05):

# ESP32-S3 VS Code 调试指南

## 概述

本文档介绍如何在 VS Code 中使用 JTAG 硬件调试器对 ESP32-S3 进行源码级调试。调试系统由三部分组成：

```
硬件调试器 ←→ OpenOCD ←→ GDB ←→ VS Code
    ↓
 ESP32-S3
```

- **硬件调试器**：通过 JTAG 接口与芯片通信（如 ESP-Prog、J-Link）
- **OpenOCD**：片上调试服务器，翻译 GDB 命令为 JTAG 信号
- **GDB**：GNU 调试器，提供断点、单步、变量查看等功能
- **VS Code**：可视化调试界面

## 硬件准备

### 1. JTAG 调试器选择

支持的调试器：
- **ESP-Prog**（推荐）：Espressif 官方调试器，原生支持
- **J-Link**：SEGGER 调试器，性能更好但需额外配置
- **FT2232H**：基于 FTDI 芯片的通用调试器

### 2. JTAG 引脚连接

ESP32-S3 默认 JTAG 引脚：

| JTAG 信号 | ESP32-S3 GPIO |
| --- | --- |
| MTDO/TDO  | GPIO39 |
| MTDI/TDI  | GPIO40 |
| MTCK/TCK  | GPIO41 |
| MTMS/TMS  | GPIO42 |
| GND | GND |
| VCC | 3.3V (可选) |

**注意**：
- 确保调试器和 ESP32-S3 共地（GND）
- VCC 连接可选，取决于调试器是否需要检测目标电压
- 这些引脚不能用于其他功能（如 GPIO、PWM）

### 3. 硬件配置检查

在 `main/Kconfig.projbuild` 中确保没有禁用 JTAG：

```kconfig
# 不要设置这个选项，否则 JTAG 会被禁用
# CONFIG_ESP_SYSTEM_DISABLE_JTAG=y
```

## 软件配置

### 1. ESP-IDF 扩展安装

1. 在 VS Code 中安装 **ESP-IDF** 扩展
2. 配置 ESP-IDF 路径（通常在 `C:\Espressif\esp-idf` 或 `~/.espressif/esp-idf`）
3. 验证工具链安装：
   ```powershell
   idf.py --version
   ```

### 2. 调试配置文件

项目的 `.vscode/launch.json` 已配置好 JTAG 调试：

```json
{
  "version": "0.2.0",
  "configurations": [
    {
      "name": "GDB",
      "type": "cppdbg",
      "request": "launch",
      "MIMode": "gdb",
      "miDebuggerPath": "${command:espIdf.getToolchainGdb}",
      "program": "${workspaceFolder}/build/${command:espIdf.getProjectName}.elf",
      "windows": {
        "program": "${workspaceFolder}\\build\\${command:espIdf.getProjectName}.elf"
      },
      "cwd": "${workspaceFolder}",
      "setupCommands": [
        {
          "text": "target remote :3333"
        },
        {
          "text": "set remote hardware-watchpoint-limit 2"
        },
        {
          "text": "mon reset halt"
        },
        {
          "text": "thb app_main"
        },
        {
          "text": "flushregs"
        }
      ],
      "externalConsole": false,
      "logging": {
        "engineLogging": true
      }
    }
  ]
}
```

#### 配置说明

| 配置项 | 说明 |
| --- | --- |
| `miDebuggerPath` | 自动获取 Xtensa GDB 路径（位于 ESP-IDF 工具链） |
| `program` | ELF 文件路径，包含调试符号 |
| `target remote :3333` | 连接 OpenOCD 的 GDB 服务器（端口 3333） |
| `set remote hardware-watchpoint-limit 2` | ESP32-S3 只支持 2 个硬件观察点 |
| `mon reset halt` | 复位芯片并立即暂停 |
| `thb app_main` | 在 `app_main()` 设置临时断点 |
| `flushregs` | 刷新寄存器缓存 |

### 3. OpenOCD 配置

ESP-IDF 扩展会自动管理 OpenOCD，但也可以手动启动：

```powershell
# 使用 ESP-Prog 调试器
openocd -f board/esp32s3-builtin.cfg

# 使用 J-Link
openocd -f interface/jlink.cfg -f target/esp32s3.cfg
```

OpenOCD 启动后会监听：
- **端口 3333**：GDB 服务器
- **端口 4444**：Telnet 命令接口

## 调试流程

### 1. 编译固件（带调试符号）

```powershell
# 确保启用调试符号
idf.py menuconfig
# Component config → Compiler options → Optimization Level → Debug (-Og)

# 编译
idf.py build

# 烧录（首次调试需要烧录固件）
idf.py -p COM3 flash
```

**重要**：优化级别选择：
- **Debug (-Og)**：最佳调试体验，但性能较低
- **Release (-O2)**：性能优先，调试时变量可能被优化掉

### 2. 启动 OpenOCD

**方法 A：使用 ESP-IDF 扩展（推荐）**

1. 按 `Ctrl+Shift+P` 打开命令面板
2. 输入 `ESP-IDF: OpenOCD Manager`
3. 选择 `Start OpenOCD`
4. 扩展会自动选择正确的配置文件

**方法 B：手动启动**

在终端运行：
```powershell
openocd -f board/esp32s3-builtin.cfg
```

成功启动后会看到类似输出：
```
Info : [esp32s3] Target halted, PC=0x40043abc
Info : starting gdb server for esp32s3 on 3333
```

### 3. 开始调试

1. **连接硬件**：确保 JTAG 调试器已连接到 ESP32-S3
2. **打开文件**：在 VS Code 中打开要调试的源文件（如 `main/main.c`）
3. **设置断点**：在代码行号左侧点击设置断点
4. **启动调试**：
   - 按 `F5` 或点击 `运行 → 启动调试`
   - 选择 `GDB` 配置
5. **等待停在断点**：程序会在 `app_main()` 函数自动停止

### 4. 调试操作

| 操作 | 快捷键 | 说明 |
| --- | --- | --- |
| 继续执行 | `F5` | 运行到下一个断点 |
| 单步跳过 | `F10` | 执行当前行，不进入函数 |
| 单步进入 | `F11` | 进入函数内部 |
| 单步跳出 | `Shift+F11` | 跳出当前函数 |
| 重启调试 | `Ctrl+Shift+F5` | 复位芯片并重新开始 |
| 停止调试 | `Shift+F5` | 结束调试会话 |

### 5. 查看变量和内存

- **变量窗口**：自动显示局部变量和全局变量
- **监视窗口**：添加自定义表达式（如 `sensor.accel_x`）
- **调用栈**：查看函数调用链
- **寄存器**：查看 CPU 寄存器值
- **内存查看器**：右键变量 → `View Memory`

## 高级技巧

### 1. 调试 FreeRTOS 任务

查看所有任务状态：

在 GDB 调试控制台（`调试控制台`）输入：
```gdb
-exec info threads
```

切换到特定任务：
```gdb
-exec thread 2
```

### 2. 硬件断点限制

ESP32-S3 只有 **2 个硬件断点**，超过会报错。解决方法：
- 使用条件断点减少断点数量
- 禁用不必要的断点
- 使用软件断点（在 Flash 中运行的代码）

### 3. 观察点（Watchpoint）

监控变量变化：

在调试控制台输入：
```gdb
-exec watch sensor.accel_x
```

当 `sensor.accel_x` 值改变时程序会暂停。

### 4. 实时变量修改

在调试时修改变量值：
1. 在 `变量` 窗口右键变量
2. 选择 `Set Value`
3. 输入新值并回车

### 5. 调试优化代码

如果必须调试 `-O2` 优化的代码：

1. 在 `menuconfig` 中启用 `-fno-inline`：
   ```
   Component config → Compiler options → 
   Disable inlining functions
   ```

2. 特定函数禁用优化：
   ```c
   __attribute__((optimize("O0")))
   void critical_function(void) {
       // 这个函数不会被优化
   }
   ```

## 常见问题

### 1. OpenOCD 连接失败

**错误**：`Error: libusb_open() failed with LIBUSB_ERROR_NOT_FOUND`

**解决**：
- 检查调试器 USB 驱动（ESP-Prog 需要 WinUSB 驱动）
- 使用 Zadig 工具安装正确驱动
- 确保只有一个 OpenOCD 实例在运行

### 2. GDB 连接超时

**错误**：`target remote :3333 timeout`

**解决**：
- 确保 OpenOCD 已启动并监听 3333 端口
- 检查防火墙是否阻止了连接
- 尝试手动启动 OpenOCD 查看错误信息

### 3. 断点无效

**现象**：设置断点后程序不停止

**原因**：
- 代码被编译器优化掉了（检查 `-O2` 优化）
- 代码在 Flash 中且未启用软件断点
- 超过硬件断点限制（最多 2 个）

**解决**：
- 使用 `-Og` 编译
- 减少同时激活的断点数量

### 4. 变量显示 `<optimized out>`

**原因**：编译器优化导致变量被优化到寄存器或删除

**解决**：
- 使用 `-Og` 优化级别
- 将关键变量声明为 `volatile`
- 在函数上添加 `__attribute__((optimize("O0")))`

### 5. 调试时芯片不断重启

**原因**：
- 看门狗未被喂狗
- JTAG 引脚配置冲突

**解决**：
- 在 `menuconfig` 中禁用调试时的看门狗：
  ```
  Component config → ESP System Settings →
  Interrupt watchdog timeout (ms) = 0
  ```
- 确保 JTAG 引脚未被其他功能占用

### 6. 调试 WiFi 或 Bluetooth 代码时卡死

**原因**：某些外设在调试暂停时会超时

**解决**：
- 在关键代码段禁用看门狗
- 使用日志而非断点调试实时代码
- 在中断处理函数中不要设置断点

## 性能对比

| 调试方式 | 优势 | 劣势 | 适用场景 |
| --- | --- | --- | --- |
| **JTAG 调试**  | 硬件断点、实时内存查看、无需修改代码 | 需要硬件调试器、速度较慢 | 复杂 Bug、底层驱动开发 |
| **串口日志** | 简单、无需额外硬件、实时性好 | 无法暂停、需修改代码 | WiFi/BLE、高频中断 |
| **Trace 跟踪** | 高速采样、不影响实时性 | 需要专业工具 | 性能分析、协议分析 |

## 最佳实践

1. **开发阶段使用 `-Og`**：保证调试体验
2. **发布前测试 `-O2`**：确保优化后功能正常
3. **关键变量标记 `volatile`**：防止被优化
4. **合理使用断点**：不要超过 2 个硬件断点
5. **调试实时代码用日志**：JTAG 会影响时序
6. **定期清理编译产物**：`idf.py fullclean` 避免调试信息不同步

## 参考资料

- [ESP-IDF JTAG 调试文档](https://docs.espressif.com/projects/esp-idf/zh_CN/latest/esp32s3/api-guides/jtag-debugging/)
- [OpenOCD 用户手册](http://openocd.org/doc/html/index.html)
- [GDB 调试指南](https://sourceware.org/gdb/current/onlinedocs/gdb/)
- ESP-Drone 项目文档：`文档/` 目录

## 项目特定配置

### ESP-Drone 调试要点

1. **双核调试**：ESP32-S3 是双核，GDB 会默认调试 PRO_CPU（核心 0）
2. **FreeRTOS 任务**：使用 `info threads` 查看所有任务
3. **关键任务**：
   - `sensorsTask`：传感器数据读取（500Hz）
   - `stabilizerTask`：控制循环（1000Hz）
   - `commanderTask`：指令处理
   - `wifilink`：WiFi 通信

4. **调试传感器**：在 `sensors_mpu6050.c` 中设置断点查看原始数据
5. **调试控制算法**：在 `controller_pid.c` 中查看 PID 输出
6. **调试估计器**：在 `estimator_kalman.c` 中查看状态估计

---

**最后更新**：2025年12月25日

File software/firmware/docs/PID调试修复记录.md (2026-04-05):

# PID 控制系统调试与修复记录

**日期**: 2026-02-28  
**平台**: ESP32-S3 + ESP-IDF v5.5.1  
**固件基础**: Crazyflie 移植版  
**飞行构型**: X 型四旋翼  

---

## 一、问题现象

桌面测试时出现：**一个电机满转、对角电机输出为 0**，且两个电机完全不同步，无法形成正常飞行姿态修正。

---

## 二、根本原因分析

经逐层排查，发现三个独立问题叠加导致了该现象：

| # | 问题 | 位置 | 影响 |
| --- | --- | --- | --- |
| 1 | Pitch 符号错误 | `controller_pid.c` | 正反馈 → 失控 |
| 2 | Rate PID 积分饱和 | `pid.h` | PID 输出恒为最大值 |
| 3 | Mixer 无修正缩放  | `power_distribution_stock.c` | 低油门时电机极差悬殊 |

---

## 三、修复详情

### 3.1 Pitch 符号错误修复

**文件**: `components/core/crazyflie/modules/src/controller_pid.c`

**问题**: 原始代码中有 `control->pitch = -control->pitch`，注释称"鼻子上仰 = pitch 为负"。经四元数严格推导该假设错误，导致 Pitch 轴形成**正反馈**。

**四元数推导过程**:
```
鼻子上仰 → 绕 Y 轴旋转 -θ (右手系)
q = (cos(θ/2), 0, -sin(θ/2), 0)

gravX = 2*(qx*qz - qw*qy)
      = 2*(0 - cos(θ/2)*(-sin(θ/2)))
      = sin(θ) > 0

pitch = asin(gravX) → 鼻子上仰时 pitch > 0 ✓
```

**修复**: 删除 `control->pitch = -control->pitch` 这一行。保留 `control->yaw = -control->yaw`（X 构型 CW 电机系数与 + 构型方向相反，需取反）。

**修复后符号链路**:
```
Roll:  飞机右倾(roll>0) → PID输出负R → r<0 → 右侧电机(M1,M4)加速 → roll减小 ✓
Pitch: 鼻子下压(pitch<0) → PID输出正P → p>0 → 前方电机(M1,M2)加速 → 鼻子上仰 ✓
Yaw:   取反后符合 X 构型 CW/CCW 电机方向 ✓
```

---

### 3.2 PID 积分饱和修复

**文件**: `components/core/crazyflie/modules/interface/pid.h`

**问题**: 原始 Rate PID 参数中 `KI=440`，`iLimit=33.3`，最大积分输出 = 440 × 33.3 ≈ **14652**，远超典型油门值（10000~25000），导致电机之间差值极大。

**修复策略 — 首飞安全参数**:

| 参数 | 原始值 | 修复后 | 说明 |
| --- | --- | --- | --- |
| Roll Rate KI | 440 | **0** | 纯 PD，消除积分饱和 |
| Pitch Rate KI | 440 | **0** | 纯 PD，消除积分饱和 |
| Roll Rate KP | 250 | 250 | 保持不变 |
| Roll Rate KD | 2.5 | 2.5 | 保持不变 |
| Roll KP (外环) | 3.5 | **6.0**  | 提高姿态响应速度 |
| Roll KI (外环) | 2.5 | **1.0**  | 降低积分贡献 |
| Roll iLimit (外环) | 20.0 | **10.0** | 限制最大积分输出 = 10°/s |
| Pitch 同 Roll | — | — | 与 Roll 相同 |
| Yaw KP | 6.0 | 6.0 | 保持 |
| Yaw KI | 1.0 | 1.0 | 保持 |
| Yaw KD | 0 | 0.35 | 加少量微分抑制震荡 |

**最终参数**（`#ifdef CONFIG_TARGET_ESP32_S2_DRONE_V1_2`）:
```c
// 内环 Rate PID
#define PID_ROLL_RATE_KP  250.0
#define PID_ROLL_RATE_KI  0.0      // 首飞: 纯PD
#define PID_ROLL_RATE_KD  2.5
#define PID_ROLL_RATE_INTEGRATION_LIMIT  33.3

#define PID_PITCH_RATE_KP  250.0
#define PID_PITCH_RATE_KI  0.0
#define PID_PITCH_RATE_KD  2.5
#define PID_PITCH_RATE_INTEGRATION_LIMIT  33.3

#define PID_YAW_RATE_KP  120.0
#define PID_YAW_RATE_KI  16.7
#define PID_YAW_RATE_KD  0.0
#define PID_YAW_RATE_INTEGRATION_LIMIT  166.7

// 外环 Attitude PID
#define PID_ROLL_KP   6.0
#define PID_ROLL_KI   1.0
#define PID_ROLL_KD   0.0
#define PID_ROLL_INTEGRATION_LIMIT  10.0

#define PID_PITCH_KP   6.0
#define PID_PITCH_KI   1.0
#define PID_PITCH_KD   0.0
#define PID_PITCH_INTEGRATION_LIMIT  10.0

#define PID_YAW_KP   6.0
#define PID_YAW_KI   1.0
#define PID_YAW_KD   0.35
#define PID_YAW_INTEGRATION_LIMIT  20.0
```

---

### 3.3 推力比例输出限幅

**文件**: `components/core/crazyflie/modules/src/controller_pid.c`

**问题**: 即使 PID 参数合理，极端情况下 R/P/Y 输出之和仍可能超过推力 T，导致某个电机输出为负（被 clamp 到 0）。

**修复**: 在 mixer 之前，根据当前推力值动态限制 R/P/Y 输出范围：

```
|R| ≤ 0.6T
|P| ≤ 0.6T
|Y| ≤ 0.2T
→ 最差电机 ≥ T - 0.3T - 0.3T - 0.2T = 0.2T（至少保留 20% 推力）
```

同时修复了一个**整数溢出 Bug**：

```c
// ❌ 错误：T > 54612 时 thr*0.6 > 32767，int16_t溢出变负数
int16_t rpLim = (int16_t)(thr * 0.6f);

// ✅ 修复：用int32_t中间变量，再clamp到INT16_MAX
int32_t rpLim32 = (int32_t)(thr * 0.6f);
int16_t rpLim = (rpLim32 > INT16_MAX) ? INT16_MAX : (int16_t)rpLim32;
```

当 T = 60000（满油门）时，若不修复，`thr * 0.6f = 36000` 截断为 `int16_t` 后变为负数（约 -29536），导致限幅逻辑反向，R 和 P 都被钳制到 -29536。修复后限幅值正确取 INT16_MAX = 32767。

---

### 3.4 Mixer 修正缩放

**文件**: `components/core/crazyflie/modules/src/power_distribution_stock.c`

**问题**: 低油门时若 `|r|+|p|+|y| > T`，某些电机计算值为负，被 `limitThrust` 强制截断到 0，产生非线性死区。

**修复**: 在 mixer 执行前等比例缩放修正量：

```c
int32_t totalCorrection = absR + absP + absY;
if (thrust > 0 && totalCorrection > thrust)
{
    float scale = (float)thrust / (float)totalCorrection;
    r = (int16_t)(r * scale);
    p = (int16_t)(p * scale);
    y = (int16_t)(y * scale);
}
```

---

## 四、陀螺仪 Y 轴取反说明

**文件**: `controller_pid.c` Line ~130

```c
attitudeControllerCorrectRatePID(
    sensors->gyro.x,
    -sensors->gyro.y,  // Y轴取反
    sensors->gyro.z,
    ...
);
```

BMI088 传感器坐标系中 gyro.y 的正方向与飞控定义的 Pitch 速率正方向相反，因此在传入 Rate PID 之前将 gyro.y 取反，确保内环误差方向正确。

---

## 五、测试结果

### 修复前（原始参数）
```
T=15000  R=-24000  P=+24000  Y=+15000
M1=0  M2=65535  M3=0  M4=0   ← 极端失衡
```

### 修复后（现行参数）
```
T=24500  R=-4000  P=+3500  Y=+200
M1=26500  M2=26000  M3=18400  M4=27000  ← 分布合理
```

输出特征：
- R 和 P 与推力成比例，有界
- 各电机差值不超过 ±30%
- 不再出现单电机满转/归零的极端情况

---

## 六、后续调参建议

### 首飞后（确认方向正确）

1. **逐步加入 Rate KI**：从 50 开始，观察抗扰能力提升
   ```c
   #define PID_ROLL_RATE_KI  50.0   // 尝试值
   #define PID_ROLL_RATE_INTEGRATION_LIMIT  20.0
   ```

2. **如响应迟钝**：适当提高 Rate KP（250 → 300）

3. **Yaw 积分漂移**：桌面测试中 Y 会缓慢累积到 ~2000~5000，飞行时重力约束会改善，若仍漂移可降低 `PID_YAW_RATE_KI`

### 调参优先级

```
1. 确认 Roll/Pitch 方向 → 2. Rate KP 粗调 → 3. 加入 Rate KI → 4. 外环 KP 细调
```

---

## 七、修改文件汇总

| 文件 | 修改内容 |
| --- | --- |
| `components/core/crazyflie/modules/src/controller_pid.c` | 删除 Pitch 取反；添加推力比例限幅；修复 int16 溢出；添加诊断日志 |
| `components/core/crazyflie/modules/interface/pid.h` | Rate KI 归零；外环 KP=6/KI=1/iLimit=10；Yaw KD=0.35 |
| `components/core/crazyflie/modules/src/power_distribution_stock.c` | 添加等比例修正缩放；添加诊断日志 |

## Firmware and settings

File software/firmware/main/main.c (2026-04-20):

/*
 * ESP-Drone Firmware
 *
 * Copyright 2019-2020  Espressif Systems (Shanghai)
 * Copyright (C) 2011-2012 Bitcraze AB
 *
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
 */

#include <stdint.h>
#include <stdio.h>
#include <stdlib.h>

#include "freertos/FreeRTOS.h"
#include "freertos/task.h"
#include "freertos/portmacro.h"
#include "nvs_flash.h"

#include "stm32_legacy.h"
#include "platform.h"
#include "system.h"
#include "esp_log.h"
#include "bmi088_spi.h"
#include "bmi088.h"
#include "spi_drv.h"
#include "sbus.h"
#include "i2cdev.h"
#define DEBUG_MODULE "APP_MAIN"
#include "debug_cf.h"

// 声明BMI088配置函数
extern bool bmi088_init_with_default_config(bmi088_dev_t *dev);

void app_main()
{
    /*
     * 初始化平台并启动系统任务
     * app_main 将初始化并启动所有功能
     */

    /* 初始化 NVS flash 为 Wi-Fi 做准备 */
    esp_err_t ret = nvs_flash_init();

    if (ret == ESP_ERR_NVS_NO_FREE_PAGES || ret == ESP_ERR_NVS_NEW_VERSION_FOUND)
    {
        ESP_ERROR_CHECK(nvs_flash_erase());
        ret = nvs_flash_init();
    }

    ESP_ERROR_CHECK(ret);

    /* 初始化平台 */
    if (platformInit() == false)
    {
        while (1)
            DEBUG_PRINT("ERROR: Platform Init Failed\n");
        ; // 如果固件运行在错误的硬件上,停止运行
    }

    /* BMI088硬件测试 - 直接读取数据验证 */
    ESP_LOGI("APP_MAIN", "=== BMI088 Hardware Test ===");

    // 初始化SPI
    spiDrvInit(SPI_DRV_HOST_DEFAULT);
    vTaskDelay(pdMS_TO_TICKS(100));

    // 创建BMI088设备结构体
    bmi088_dev_t bmi088_dev = {0};

    // 使用默认配置初始化BMI088
    if (bmi088_init_with_default_config(&bmi088_dev))
    {
        ESP_LOGI("APP_MAIN", "BMI088 init SUCCESS");

        // 读取10次数据验证
        for (int i = 0; i < 10; i++)
        {
            bmi088_sensor_data_t gyro_data, acc_data;

            if (bmi088_spi_read_gyro_data(&bmi088_dev, &gyro_data) &&
                bmi088_spi_read_acc_data(&bmi088_dev, &acc_data))
            {
                ESP_LOGI("APP_MAIN", "[Test %d] Gyro: X=%d Y=%d Z=%d | Accel: X=%d Y=%d Z=%d",
                         i + 1, gyro_data.x, gyro_data.y, gyro_data.z,
                         acc_data.x, acc_data.y, acc_data.z);
            }
            else
            {
                ESP_LOGE("APP_MAIN", "[Test %d] Failed to read sensor data", i + 1);
            }

            vTaskDelay(pdMS_TO_TICKS(100));
        }

        ESP_LOGI("APP_MAIN", "=== BMI088 Test Complete ===");
    }
    else
    {
        ESP_LOGE("APP_MAIN", "BMI088 init FAILED!");
    }

    /* SBUS硬件测试 - 初始化并等待数据 */
    ESP_LOGI("APP_MAIN", "=== SBUS Hardware Test ===");

    sbusInit();

    if (sbusTest())
    {
        ESP_LOGI("APP_MAIN", "SBUS init SUCCESS, waiting for receiver data...");

        sbusFrame_t frame;
        int framesReceived = 0;

        // 尝试读取10次数据，每次等待500ms
        for (int i = 0; i < 10; i++)
        {
            if (sbusReadFrame(&frame, 500) == pdTRUE)
            {
                framesReceived++;
                ESP_LOGI("APP_MAIN", "[Test %d] CH1=%4d CH2=%4d CH3=%4d CH4=%4d | FS=%d FL=%d",
                         framesReceived,
                         frame.channels[0], frame.channels[1],
                         frame.channels[2], frame.channels[3],
                         frame.failsafe, frame.frameLost);

                // 如果已经收到3帧有效数据，测试通过
                if (framesReceived >= 3)
                {
                    ESP_LOGI("APP_MAIN", "SBUS receiving data OK!");
                    break;
                }
            }
            else
            {
                ESP_LOGW("APP_MAIN", "[Attempt %d] No SBUS data received (timeout 500ms)", i + 1);
            }
        }

        if (framesReceived == 0)
        {
            ESP_LOGW("APP_MAIN", "SBUS: No data received - check receiver connection");
            ESP_LOGW("APP_MAIN", "  - Verify receiver is powered and bound to transmitter");
            ESP_LOGW("APP_MAIN", "  - Verify SBUS wire connected to RX pin");
        }

        ESP_LOGI("APP_MAIN", "=== SBUS Test Complete (frames: %d) ===", framesReceived);
    }
    else
    {
        ESP_LOGE("APP_MAIN", "SBUS init FAILED!");
    }

    /* 启动系统任务（QMC5883P 已移至 sensorsDeviceInit 统一初始化） */
    systemLaunch();
}

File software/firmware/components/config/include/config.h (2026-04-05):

/**
 *
 * ESP-Drone Firmware
 *
 * Copyright 2019-2020  Espressif Systems (Shanghai)
 * Copyright (C) 2011-2012 Bitcraze AB
 *
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
 * config.h - Main configuration file
 *
 * This file define the default configuration of the copter
 * It contains two types of parameters:
 * - The global parameters are globally defined and independent of any
 *   compilation profile. An example of such define could be some pinout.
 * - The profiled defines, they are parameter that can be specific to each
 *   dev build. The vanilla build is intended to be a "customer" build without
 *   fancy spinning debugging stuff. The developers build are anything the
 *   developer could need to debug and run his code/crazy stuff.
 *
 * The golden rule for the profile is NEVER BREAK ANOTHER PROFILE. When adding a
 * new parameter, one shall take care to modified everything necessary to
 * preserve the behavior of the other profiles.
 *
 * For the flag. T_ means task. H_ means HAL module. U_ would means utils.
 */

#ifndef CONFIG_H_
#define CONFIG_H_
// #include "nrf24l01.h"

// #include "trace.h"
#include "usec_time.h"
#include "sdkconfig.h"

#define PROTOCOL_VERSION 4
#define QUAD_FORMATION_X

#ifdef CONFIG_TARGET_ESPLANE_V2_S2
#ifndef CONFIG_IDF_TARGET_ESP32S2
#error "ESPLANE_V2 hardware with ESP32S2 onboard"
#endif
#elif defined(CONFIG_TARGET_ESPLANE_V1)
#ifndef CONFIG_IDF_TARGET_ESP32
#error "ESPLANE_V1 hardware with ESP32 onboard"
#endif
#elif defined(CONFIG_TARGET_ESP32_S2_DRONE_V1_2)
#ifdef CONFIG_IDF_TARGET_ESP32
#error "ESP32_S2_DRONE_V1_2 hardware with ESP32S2/S3 onboard"
#endif
#endif

#ifdef STM32F4XX
#define CONFIG_BLOCK_ADDRESS (2048 * (64 - 1))
#define MCU_ID_ADDRESS 0x1FFF7A10
#define MCU_FLASH_SIZE_ADDRESS 0x1FFF7A22
#ifndef FREERTOS_HEAP_SIZE
#define FREERTOS_HEAP_SIZE 20000
#endif
#define FREERTOS_MIN_STACK_SIZE 150 // M4-FPU register setup is bigger so stack needs to be bigger
#define FREERTOS_MCU_CLOCK_HZ 168000000

#define configGENERATE_RUN_TIME_STATS 1
#define portCONFIGURE_TIMER_FOR_RUN_TIME_STATS() initUsecTimer()
#define portGET_RUN_TIME_COUNTER_VALUE() usecTimestamp()
#endif

// #define DEBUG_UDP
// #define DEBUG_EP2

// Task priorities. Higher number higher priority
// system state tasks
#define SYSTEM_TASK_PRI 1
#define PM_TASK_PRI 1
#define LEDSEQCMD_TASK_PRI 1
// communication TX tasks
#define UDP_TX_TASK_PRI 2
#define CRTP_TX_TASK_PRI 2
// communication RX tasks
#define UDP_RX_TASK_PRI 2
#define EXTRX_TASK_PRI 2
#define UART2_TASK_PRI 2
#define SYSLINK_TASK_PRI 2
#define USBLINK_TASK_PRI 2
#define WIFILINK_TASK_PRI 2
#define CRTP_RX_TASK_PRI 2
#define CMD_HIGH_LEVEL_TASK_PRI 3
#define INFO_TASK_PRI 2
#define LOG_TASK_PRI 2
#define MEM_TASK_PRI 2
#define PARAM_TASK_PRI 2
// sensors and stabilize related tasks
#define PROXIMITY_TASK_PRI 5
#define FLOW_TASK_PRI 5
#define ZRANGER2_TASK_PRI 5
#define ZRANGER_TASK_PRI 5
#define SENSORS_TASK_PRI 6
#define STABILIZER_TASK_PRI 7
#define KALMAN_TASK_PRI 4

// the kalman filter consumes a lot of CPU
// for single core systems, we need to lower the priority
#if CONFIG_FREERTOS_UNICORE
#undef KALMAN_TASK_PRI
#define KALMAN_TASK_PRI 1
#endif

// Task names
#define CMD_HIGH_LEVEL_TASK_NAME "CMDHL"
#define CRTP_RX_TASK_NAME "CRTP-RX"
#define CRTP_TX_TASK_NAME "CRTP-TX"
#define EXTRX_TASK_NAME "EXTRX"
#define FLOW_TASK_NAME "FLOW"
#define KALMAN_TASK_NAME "KALMAN"
#define LEDSEQCMD_TASK_NAME "LEDSEQCMD"
#define LOG_TASK_NAME "LOG"
#define MEM_TASK_NAME "MEM"
#define PARAM_TASK_NAME "PARAM"
#define PM_TASK_NAME "PWRMGNT"
#define PROXIMITY_TASK_NAME "PROXIMITY"
#define SENSORS_TASK_NAME "SENSORS"
#define STABILIZER_TASK_NAME "STABILIZER"
#define SYSLINK_TASK_NAME "SYSLINK"
#define SYSTEM_TASK_NAME "SYSTEM"
#define UART2_TASK_NAME "UART2"
#define UDP_RX_TASK_NAME "UDP_RX"
#define UDP_TX_TASK_NAME "UDP_TX"
#define USBLINK_TASK_NAME "USBLINK"
#define WIFILINK_TASK_NAME "WIFILINK"
#define ZRANGER2_TASK_NAME "ZRANGER2"
#define ZRANGER_TASK_NAME "ZRANGER"
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

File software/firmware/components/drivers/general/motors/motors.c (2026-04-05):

/**
 *
 * ESP-Drone Firmware
 *
 * Copyright 2019-2020  Espressif Systems (Shanghai)
 * Copyright (C) 2011-2012 Bitcraze AB
 *
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
 * motors.c - Motor driver (MCPWM for Brushless ESC)
 *
 */

#include <stdbool.h>

#include "freertos/FreeRTOS.h"
#include "freertos/task.h"

#include "esp_attr.h"
#include "esp_system.h"

#include "driver/mcpwm_prelude.h"

#include "stm32_legacy.h"
#include "motors.h"
#include "pm_esplane.h"
#include "log.h"
#include "param.h"
#define DEBUG_MODULE "MOTORS"
#include "debug_cf.h"

/******** MCPWM ESC Configuration ********/
#define ESC_TIMEBASE_RESOLUTION_HZ 1000000
#define ESC_TIMEBASE_PERIOD 2500
#define ESC_PULSE_MIN_US 1000
#define ESC_PULSE_MAX_US 2000

static const int motor_gpios[NBR_OF_MOTORS] = {
    MOTOR1_GPIO,
    MOTOR2_GPIO,
    MOTOR3_GPIO,
    MOTOR4_GPIO};

static mcpwm_timer_handle_t motor_timers[NBR_OF_MOTORS] = {NULL};
static mcpwm_oper_handle_t motor_operators[NBR_OF_MOTORS] = {NULL};
static mcpwm_cmpr_handle_t motor_comparators[NBR_OF_MOTORS] = {NULL};
static mcpwm_gen_handle_t motor_generators[NBR_OF_MOTORS] = {NULL};

static uint8_t escCalibRequest = 0;
static bool escCalibActive = false;

static uint32_t motor_pulse_us[NBR_OF_MOTORS] = {ESC_PULSE_MIN_US, ESC_PULSE_MIN_US, ESC_PULSE_MIN_US, ESC_PULSE_MIN_US};
uint32_t motor_ratios[NBR_OF_MOTORS] = {0, 0, 0, 0};

void motorsBeep(int id, bool enable, uint16_t frequency, uint16_t ratio);
static void motorsHandleEscCalibCommand(void);
static uint16_t pulseWidthToThrust(uint32_t pulse_us);
static inline void motorSetPulseWidthRaw(uint32_t id, uint32_t pulse_us);
static inline void motorsSetAllPulseWidthRaw(uint32_t pulse_us);
const MotorPerifDef **motorMap;

const uint32_t MOTORS[] = {MOTOR_M1, MOTOR_M2, MOTOR_M3, MOTOR_M4};

const uint16_t testsound[NBR_OF_MOTORS] = {0, 0, 0, 0};

static bool isInit = false;

static inline void motorSetPulseWidthRaw(uint32_t id, uint32_t pulse_us)
{
    ASSERT(id < NBR_OF_MOTORS);
    ESP_ERROR_CHECK(mcpwm_comparator_set_compare_value(motor_comparators[id], pulse_us));
    motor_pulse_us[id] = pulse_us;
    motor_ratios[id] = pulseWidthToThrust(pulse_us);
}

static inline void motorsSetAllPulseWidthRaw(uint32_t pulse_us)
{
    for (uint32_t i = 0; i < NBR_OF_MOTORS; i++)
    {
        motorSetPulseWidthRaw(i, pulse_us);
    }
}

static uint32_t thrustToPulseWidth(uint16_t thrust)
{
    return ESC_PULSE_MIN_US + ((uint32_t)thrust * (ESC_PULSE_MAX_US - ESC_PULSE_MIN_US)) / 65535;
}

static uint16_t pulseWidthToThrust(uint32_t pulse_us)
{
    if (pulse_us <= ESC_PULSE_MIN_US)
        return 0;
    if (pulse_us >= ESC_PULSE_MAX_US)
        return 65535;
    return (uint16_t)(((pulse_us - ESC_PULSE_MIN_US) * 65535) / (ESC_PULSE_MAX_US - ESC_PULSE_MIN_US));
}

void motorsInit(const MotorPerifDef **motorMapSelect)
{
    if (isInit)
    {
        return;
    }

    motorMap = motorMapSelect;

    for (int i = 0; i < NBR_OF_MOTORS; i++)
    {
        mcpwm_timer_config_t timer_config = {
            .group_id = i / 2,
            .clk_src = MCPWM_TIMER_CLK_SRC_DEFAULT,
            .resolution_hz = ESC_TIMEBASE_RESOLUTION_HZ,
            .period_ticks = ESC_TIMEBASE_PERIOD,
            .count_mode = MCPWM_TIMER_COUNT_MODE_UP,
        };
        ESP_ERROR_CHECK(mcpwm_new_timer(&timer_config, &motor_timers[i]));

        mcpwm_operator_config_t operator_config = {
            .group_id = i / 2,
        };
        ESP_ERROR_CHECK(mcpwm_new_operator(&operator_config, &motor_operators[i]));

        ESP_ERROR_CHECK(mcpwm_operator_connect_timer(motor_operators[i], motor_timers[i]));

        mcpwm_comparator_config_t comparator_config = {
            .flags.update_cmp_on_tez = true,
        };
        ESP_ERROR_CHECK(mcpwm_new_comparator(motor_operators[i], &comparator_config, &motor_comparators[i]));

        mcpwm_generator_config_t generator_config = {
            .gen_gpio_num = motor_gpios[i],
        };
        ESP_ERROR_CHECK(mcpwm_new_generator(motor_operators[i], &generator_config, &motor_generators[i]));

        ESP_ERROR_CHECK(mcpwm_comparator_set_compare_value(motor_comparators[i], ESC_PULSE_MIN_US));

        ESP_ERROR_CHECK(mcpwm_generator_set_action_on_timer_event(
            motor_generators[i],
            MCPWM_GEN_TIMER_EVENT_ACTION(MCPWM_TIMER_DIRECTION_UP, MCPWM_TIMER_EVENT_EMPTY, MCPWM_GEN_ACTION_HIGH)));
        ESP_ERROR_CHECK(mcpwm_generator_set_action_on_compare_event(
            motor_generators[i],
            MCPWM_GEN_COMPARE_EVENT_ACTION(MCPWM_TIMER_DIRECTION_UP, motor_comparators[i], MCPWM_GEN_ACTION_LOW)));

        ESP_ERROR_CHECK(mcpwm_timer_enable(motor_timers[i]));
        ESP_ERROR_CHECK(mcpwm_timer_start_stop(motor_timers[i], MCPWM_TIMER_START_NO_STOP));

        motor_pulse_us[i] = ESC_PULSE_MIN_US;
        motor_ratios[i] = 0;
    }

    DEBUG_PRINT("MCPWM ESC motors initialized (400Hz, 1000-2000us)\\n");
    DEBUG_PRINT("All motors set to MIN throttle (1000us), waiting for ESC arm...\\n");
    vTaskDelay(pdMS_TO_TICKS(500));
    DEBUG_PRINT("ESC arm complete.\\n");

    isInit = true;
}

void motorsDeInit(const MotorPerifDef **motorMapSelect)
{
    (void)motorMapSelect;

    for (int i = 0; i < NBR_OF_MOTORS; i++)
    {
        if (motor_timers[i] != NULL)
        {
            mcpwm_timer_start_stop(motor_timers[i], MCPWM_TIMER_STOP_EMPTY);
            mcpwm_timer_disable(motor_timers[i]);
            mcpwm_del_generator(motor_generators[i]);
            mcpwm_del_comparator(motor_comparators[i]);
            mcpwm_del_operator(motor_operators[i]);
            mcpwm_del_timer(motor_timers[i]);
            motor_timers[i] = NULL;
        }
    }
    isInit = false;
    escCalibActive = false;
}

bool motorsTest(void)
{
    int i;

    for (i = 0; i < sizeof(MOTORS) / sizeof(*MOTORS); i++)
    {
        motorsSetRatio(MOTORS[i], MOTORS_TEST_RATIO);
        vTaskDelay(M2T(MOTORS_TEST_ON_TIME_MS));
        motorsSetRatio(MOTORS[i], 0);
        vTaskDelay(M2T(MOTORS_TEST_DELAY_TIME_MS));
    }

    return isInit;
}

void motorsSetRatio(uint32_t id, uint16_t ithrust)
{
    if (isInit)
    {
        motorsHandleEscCalibCommand();

        ASSERT(id < NBR_OF_MOTORS);

        if (escCalibActive)
        {
            // Block normal outputs while ESC calibration is active.
            return;
        }

        uint32_t pulse_us = thrustToPulseWidth(ithrust);

        motorSetPulseWidthRaw(id, pulse_us);
        motor_ratios[id] = ithrust;

#ifdef DEBUG_EP2
        DEBUG_PRINT_LOCAL("Motor %d: thrust=%d, pulse=%ldus\n", id, ithrust, pulse_us);
#endif
    }
}

int motorsGetRatio(uint32_t id)
{
    ASSERT(id < NBR_OF_MOTORS);
    return pulseWidthToThrust(motor_pulse_us[id]);
}
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

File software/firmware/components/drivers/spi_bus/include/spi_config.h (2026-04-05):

#ifndef __SPI_CONFIG_H__
#define __SPI_CONFIG_H__

#include "spi_drv.h"

#ifdef __cplusplus
extern "C"
{
#endif

// ======================== SPI总线引脚配置 ========================
// SPI2总线引脚配置（推荐用于外设）
#define SPI_BUS_SCLK_PIN CONFIG_SPI_PIN_CLK  // GPIO12 - 时钟线
#define SPI_BUS_MOSI_PIN CONFIG_SPI_PIN_MOSI // GPIO11 - 主机输出
#define SPI_BUS_MISO_PIN CONFIG_SPI_PIN_MISO // GPIO13 - 主机输入

// SPI主机选择
#define SPI_BUS_HOST_ID SPI2_HOST
#define SPI_BUS_USE_DMA true
#define SPI_BUS_MAX_TRANSFER 4096

// ======================== CS片选引脚配置 ========================
// BMI088传感器CS引脚
#define BMI088_ACCEL_CS_PIN CONFIG_SPI_PIN_CS0 // GPIO45 - BMI088加速度计CS
#define BMI088_GYRO_CS_PIN CONFIG_SPI_PIN_CS1  // GPIO10 - BMI088陀螺仪CS

// ======================== SPI传输速率配置 ========================
// BMI088传输速率
#define BMI088_SPI_FREQ_HZ SPI_BAUDRATE_10MHZ
#define BMI088_SPI_MODE SPI_MODE_0
#define BMI088_SPI_QUEUE_SIZE 8

    // ======================== 配置获取函数 ========================
    /**
     * @brief 获取SPI总线配置
     * @return SPI总线配置指针
     * @note 使用静态变量避免多次初始化
     */
    static inline spi_drv_bus_config_t *get_spi_bus_config(void)
    {
        static spi_drv_bus_config_t config = {
            .host_id = SPI_BUS_HOST_ID,
            .miso_pin = SPI_BUS_MISO_PIN,
            .mosi_pin = SPI_BUS_MOSI_PIN,
            .sclk_pin = SPI_BUS_SCLK_PIN,
            .use_dma = SPI_BUS_USE_DMA,
            .max_transfer_sz = SPI_BUS_MAX_TRANSFER,
            .is_bus_initialized = false};
        return &config;
    }

    /**
     * @brief 获取BMI088加速度计SPI设备配置
     * @return 设备配置指针
     */
    static inline const spi_drv_device_config_t *get_bmi088_accel_spi_config(void)
    {
        static const spi_drv_device_config_t config = {
            .cs_pin = BMI088_ACCEL_CS_PIN,
            .clock_speed_hz = BMI088_SPI_FREQ_HZ,
            .mode = BMI088_SPI_MODE,
            .queue_size = BMI088_SPI_QUEUE_SIZE};
        return &config;
    }

    /**
     * @brief 获取BMI088陀螺仪SPI设备配置
     * @return 设备配置指针
     */
    static inline const spi_drv_device_config_t *get_bmi088_gyro_spi_config(void)
    {
        static const spi_drv_device_config_t config = {
            .cs_pin = BMI088_GYRO_CS_PIN,
            .clock_speed_hz = BMI088_SPI_FREQ_HZ,
            .mode = BMI088_SPI_MODE,
            .queue_size = BMI088_SPI_QUEUE_SIZE};
        return &config;
    }

#ifdef __cplusplus
}
#endif

#endif /* __SPI_CONFIG_H__ */

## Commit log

2025-10-16 初始化项目，esp_drone源码未改
    [BOM(0.2)_ESP32-S2-Drone_V1.2_20200512.xlsx, BOM_200616.xlsx, SCH_ESP32_S2_Drone_Flow_Deck_V1.1.DSN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]
2025-10-22 10.22 主要修改espnow文件，适配v5.5.1
2025-10-22 10.22 将managed_components提交，保存修改
2025-10-29 10.29 加入jy901b驱动，还未改为线程保护式
2025-11-03 11.3 加入了jy901的驱动，尝试接入硬件抽象层
2025-11-11 11.11使用BMI088
2025-11-13 11.13 新的SPI驱动
2025-11-14 11.14 暂不报错
2025-11-15 11.15 完成bmi088设计
2025-11-16 11.17 暂时完成sensors任务
2025-11-17 11.17 切换仓库
2025-11-17 11.18 完成数据采集任务，编译无报错
2025-11-19 11.19 尝试扩容，实现硬件平台匹配
    [partitions.csv]
2025-11-19 11.19 删除多余文件
    [BOM(0.2)_ESP32-S2-Drone_V1.2_20200512.xlsx, BOM_200616.xlsx, SCH_ESP32_S2_Drone_Flow_Deck_V1.1.DSN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]
2025-11-29 11.29 尝试修改电机
2025-11-29 11.19电机修改完成
2025-12-01 12.1 修改电机程序完成，编译无报错
2025-12-04 12.4 尝试增加外部遥控器
2025-12-05 12.5 已加入外部遥控器控制，编译无报错
2025-12-21 12.21 补充大量文档，测试BMI088成功
2025-12-21 12.21 bmi088中断读取有问题
2025-12-21 12.21 bmi088读取正常，仅中断读取有问题
2025-12-23 12.23 bmi088配置完成，输出正常
2025-12-23 12.23 清除多余代码
2025-12-25 12.25 姿态解算可以输出数据，气压计仍然有问题
2025-12-25 12.25 姿态解算正常
2025-12-25 12.25 融合气压计后的高度异常，不好调试，暂且搁置
2025-12-25 12.25 配置完开发环境，可以进行调试
2026-01-09 1.9 配置gitlab
2026-01-09 1.9 配置gitignore
2026-01-09 1.9 无法解决esp_now问题
2026-01-11 1.11 遥控器无问题，SBUS正确解析
2026-01-12 1.12 修改项目文件，删除多余的驱动，增减MTF01光流驱动
2026-01-12 1.12 mtf01数据读取的实现，接入卡尔曼估计器，未测试
2026-01-13 1.13 完成光流数据测试，高度数据差4cm
2026-01-13 1.13 测试完电机输出，已完成外设输出测试
2026-01-13 1.13 删除部分日志输出
2026-01-13 1.13 电机输出正常，修改了PID数值和反转Roll/Pitch控制方向
2026-01-14 1.14 姿态解算算法存在问题，尝试解决
2026-01-14 1.14 姿态解算结果正确，yaw漂移和误差未解决，Mahony和卡尔曼都可以正常解算出姿态角度
2026-01-14 1.14 增加了动态校准陀螺仪部分
2026-01-14 1.14 姿态解算算法极限，roll，pitch已无问题，yaw移动角度无误差，自偏移已经很小，尝试更激进的算法
2026-01-17 1.17 ms5611测试，解决CSB悬空问题，原始数据正常，但缺乏数据处理，高度输出异常
2026-01-17 1.17 禁用 IDLE 任务看门狗检查，因为高优先级任务（SENSORS、STABILIZER）占用了 CPU0 所有时间
2026-01-17 1.17 所以外设模块测试通过,小改pid参数
2026-01-21 1.20 尝试加入服务器与sta模式，未测试
2026-01-21 1.20 删除esp_now的相关代码，取消游戏手柄支持，减少网络链路负担
2026-01-21 1.21 修复很多通信部分的潜在问题，同时加回硬件看门狗，以保证安全性，任务占用问题同步修改
2026-01-21 1.21 远程服务器测试通过，上传例程
2026-01-21 1.21 修改一部分远程服务器数据
2026-01-26 1.26 整个板子测试通过，ms5611，bmi088测试都通过，开始改坐标系
2026-01-27 1.27 修正了关于bmi088安装造成的坐标系映射错误
2026-01-27 1.28 为前端界面增加模型显示，为遥控器添加飞行模式切换
2026-01-28 1.28 新的前端界面和远程服务器协议
2026-01-28 1.28 增加更加复杂的状态控制和显示
2026-01-31 1.30-1.31 为服务器添加udp广播功能，自动连接正常IP地址，发现SBUS遥控器安全问题，添加断连保护
2026-01-31 1.31 遥控器控制无问题，增加了断线检测机制，同步显示在前端
2026-02-02 2.1 修复遥控器判断断连的bug
2026-02-02 2.2 整个重构网站部分，模块化设计，增加电机测试和数值输出
2026-02-02 2.2 整个电机测试，输出值查看调试都完成，差实物测试
2026-02-03 2.3 为前端界面增加高度与速度输出
2026-02-03 2.3 完成了高度数据融合，现在能正常得到和显示高度，现在卡尔曼完全相信tof
2026-02-03 2.3 完成了速度数据测试，可以进行定点模式了
2026-02-04 2.4 修复电机启动校准问题
2026-02-28 2.28 修改混控公式错误的问题
2026-02-28 2.28 修复电机PID输出问题，输出接近正常
2026-03-01 3.1 混控器，坐标系转换都无问题，开始控制pid参数
2026-03-02 3.2 PID参数正常，输出正常，继续优化imu姿态解算部分的算法
2026-03-10 3.10 更新了卡尔曼滤波，与项目文件配置
2026-03-10 3.10 完成前端的pid调参界面
2026-03-16 3.16 增加足够的失控保护，已通过测试；修改电机底层，ecs校准作为新功能加入地面站控制
2026-03-16 3.16 优化PID调参界面，但不好使
2026-03-16 3.16 优化服务器端，使用TCP发送重要数据，使用UDP发送遥感数据，提升速度
2026-03-17 3.17 vofa+UDP转发完成设计，方便调参
2026-03-17 3.17 调试好了内环pid参数
2026-03-17 3.17 增加了软件技术报告
2026-03-17 3.18 解决了卡尔曼估计器中的致命bug，核心问题：Kalman 预测步骤有两个分支 地面模式：PX += dt × (acc.x − g·R[2][0]) → 加速度计与重力互相抵消 → PX ≈ 0 正确。飞行模式：PX += dt × (0 − g·R[2][0]) → 丢弃 acc.x → 速度疯狂发散 错误，现在完全改用地面模式
2026-03-21 3.22 新的机架，修复了pid调参问题
    [pid_profile.json]
2026-03-23 3.23 新的安全保护措施，解锁后高油门拦截
    [pid_profile.json]
2026-03-24 3.24 尝试加入陷波滤波器去除角速度噪音的干扰，同时降低了电机测试的转速，安全
    [pid_profile.json]
2026-03-25 3.25 提高了遥感数据发送频率，方便调参，并且分析了频谱图，加入了合适的陷波器频率，消除了高频噪音
    [pid_profile.json]
2026-03-25 3.26 提升了PID控制频率，解决了PID运算中的角速度与角度符号相反的问题，完成了初步调参，可用
    [pid_profile.json]
2026-03-26 3.27 PID都调好了，考虑到yaw的问题，尝试加入磁力计，尝试更多的调试和实地测试
    [pid_profile.json]
2026-03-27 3.27 尝试开始加入磁力计驱动
2026-04-04 47.4 新的卡尔曼估计器
    [pid_profile.json]
2026-04-04 4.4 新的状态机管理，重构了部分地面站代码
    [pid_profile.json]
2026-04-05 4.5 新的，经过整理的新仓库
    [5045 CCW.ipt, 5045 CW.ipt, MOTOR_1806.iam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]
2026-04-05 4.5 提交主分支
2026-04-11 4.11 更新.gitignore
2026-04-20 4.20 很多修改
    [pid_profile.json, 上板.0002.ipt, 上板.0004.ipt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]
2026-04-28 4.28 完成硬件设计，更新文档
    [pid_profile.json]

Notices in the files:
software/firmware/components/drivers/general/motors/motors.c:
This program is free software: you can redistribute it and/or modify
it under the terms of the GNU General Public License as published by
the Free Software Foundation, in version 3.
